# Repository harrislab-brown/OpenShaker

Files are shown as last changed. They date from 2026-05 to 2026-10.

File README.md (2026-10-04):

# OpenShaker

OpenShaker is a low-cost, flexure-guided vibration platform for fluid-mechanics experiments. It uses an affordable base shaker, a compliant stinger, and two disk flexures to reduce unwanted horizontal motion so that the bath moves predominantly in the vertical direction.

The project is designed to be reproducible and adaptable. This repository contains the 3D-print files, mechanical models, flexure geometry, control and analysis code, parts information, and build documentation needed to reproduce the current system.

<p align="center">
  Assembled OpenShaker system
</p>

> [!WARNING]
> OpenShaker combines moving hardware, a power amplifier, fabricated spring-steel flexures, power tools, and nearby liquids. Read the [safety guidance](https://github.com/harrislab-brown/OpenShaker/wiki/1.-Safety) before fabrication or operation. Inspect and tighten the assembly before every run, keep electronics dry, know how to stop the amplifier and software quickly, and begin new tests with conservative settings.

## How the system works

1. A 50 W base shaker, driven by an external amplifier, supplies the vibration.
2. A thin music-wire stinger transfers vertical motion while remaining compliant in the horizontal plane.
3. Two spiral disk flexures guide the bath assembly and resist planar motion.
4. Two bath-mounted LSM6DS3 accelerometers measure the response at separate locations.
5. A VibeCheck controller and the supplied Python code adjust drive amplitude to reach a target Bath 1 Z-axis acceleration while recording both sensors for later comparison.

This arrangement is intended to provide a defined and repeatable input for experiments involving vertically forced fluids. It is a research platform under active development, not a calibrated commercial vibration table.

## Start here

The [OpenShaker wiki](https://github.com/harrislab-brown/OpenShaker/wiki) contains the complete build and operating instructions. New users should follow the pages in this order:

1. [Safety](https://github.com/harrislab-brown/OpenShaker/wiki/1.-Safety)
2. [Required Tools](https://github.com/harrislab-brown/OpenShaker/wiki/2.-Required-Tools)
3. [Complete Parts List](https://github.com/harrislab-brown/OpenShaker/wiki/3.-Complete-Parts-List)
4. [3D Printing Guide](https://github.com/harrislab-brown/OpenShaker/wiki/4.-3D-Printing-Guide)
5. [Aluminum Extrusion and Bass Shaker Preparation](https://github.com/harrislab-brown/OpenShaker/wiki/5.-Aluminum-Extrusion-and-Bass-Shaker-Preparation)
6. [Laser Cutting the Disk Flexures](https://github.com/harrislab-brown/OpenShaker/wiki/6.-Laser-Engraving-for-Disk-Flexure-Cutting)
7. [Shaker Assembly Guide](https://github.com/harrislab-brown/OpenShaker/wiki/7.-Shaker-Assembly-Guide)
8. [Python, PID, and Plotting Overview](https://github.com/harrislab-brown/OpenShaker/wiki/8.-Python,-PID,-and-Plotting-Overview)
9. [Shaker Performance](https://github.com/harrislab-brown/OpenShaker/wiki/9.-Shaker-Performance)
10. [Ideas and Future Work](https://github.com/harrislab-brown/OpenShaker/wiki/9.1-Ideas-and-Future-Work)

## Repository contents

| Location | Contents |
| --- | --- |
| [`3D Print STLs`](https://github.com/harrislab-brown/OpenShaker/tree/main/3D%20Print%20STLs) | Individual printable parts |
| [`Bambu Print Files`](https://github.com/harrislab-brown/OpenShaker/tree/main/Bambu%20Print%20Files) | Prepared Bambu Studio project files and build plates |
| [`Code`](https://github.com/harrislab-brown/OpenShaker/tree/main/Code) | Current sweep-control, data-collection, setup, and plotting scripts |
| [`Flexure Files`](https://github.com/harrislab-brown/OpenShaker/tree/main/Flexure%20Files) | Disk-flexure geometry for fabrication |
| [`Fusion Files`](https://github.com/harrislab-brown/OpenShaker/tree/main/Fusion%20Files) | Editable mechanical design files |
| [`accelerometer_3_files)`](https://github.com/harrislab-brown/OpenShaker/tree/main/accelerometer_3_files) | Experimental three-sensor data-collection work |
| [Wiki](https://github.com/harrislab-brown/OpenShaker/wiki) | Parts, fabrication, assembly, software, safety, and performance documentation |

## Software quick start

Go to 8. [Python, PID, and Plotting Overview](https://github.com/harrislab-brown/OpenShaker/wiki/8.-Python,-PID,-and-Plotting-Overview)

## Documented performance configuration

The comparison sweeps currently published in the wiki use the following configuration:

| Component or setting | Reference value |
| --- | --- |
| Flexures | Two three-arm spiral flexures, 180° relative orientation |
| Flexure material | 1095 blue-tempered spring steel, 0.010 in (0.254 mm) thick |
| Stinger | 100 mm of 0.033 in music wire |
| Threaded support rod | 110 mm long, 1/4 in diameter |
| Standard bath | 100 mm, approximately 0.070 kg total moving bath mass |
| Sensors | Two LSM6DS3 accelerometers on the bath assembly |
| Example sweep | 25–300 Hz in 5 Hz increments, 5000 Hz sensor rate, 1.0 G peak target |

## Fabrication notes

- The frame uses 2020 aluminum extrusion. The documented cut list includes four 400 mm columns and fourteen 190 mm horizontal or shelf members.
- The standard build uses 19 unique printed part types and 32 required printed pieces, or 34 when both optional pieces are included.
- The original flexures were cut from 0.010 in 1095 blue-tempered spring steel using the supplied 60 mm disk-flexure geometry.
- Flexure material, thickness, cutting quality, bath mass, and assembly alignment can all change the system response. Treat substitutions as new configurations that require cautious testing.

## Data produced by a sweep

The PID script creates a timestamped CSV containing:

- sample time;
- commanded frequency and drive amplitude;
- sensor channel (`0` for Bath 1 and `2` for Bath 2); and
- raw X-, Y-, and Z-axis acceleration in G.

The plotting script groups the data by frequency, calculates AC RMS response, compares the two Z-axis measurements, evaluates combined planar motion, and reports the planar-to-Z ratio. It also saves high-resolution sweep plots and paginated time traces.

## Project status and support

OpenShaker is under active development. The wiki describes the current two-bath-sensor workflow; the `THIRD SENSOR (Data Collection)` folder contains separate experimental work. Check the script settings and wiki before building or running the system because filenames, procedures, and reference configurations may continue to change.

If you find an error or have a reproducibility problem, [open a GitHub issue](https://github.com/harrislab-brown/OpenShaker/issues) and include:

- the step or script you were using;
- your operating system and Python version;
- the mechanical configuration and test settings; and
- the complete error message or relevant data figure.

## License

A project license has not yet been added to this repository. Until one is included, contact the maintainers before redistributing or adapting the project files.

## Acknowledgments

OpenShaker is being developed by the [Harris Lab at Brown University](https://github.com/harrislab-brown). The control and measurement workflow uses the VibeCheck platform.

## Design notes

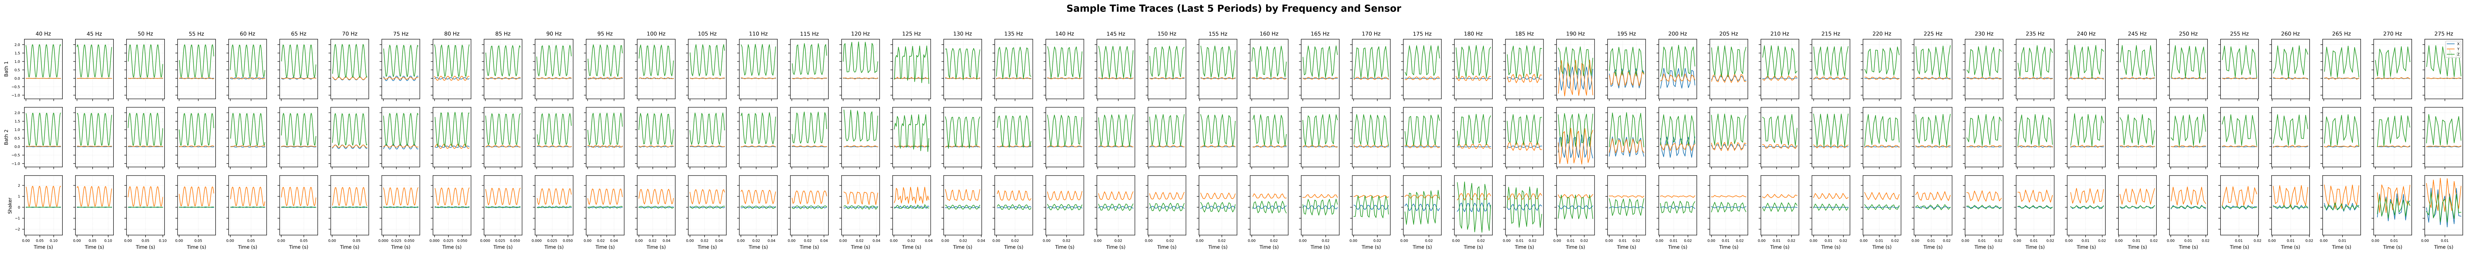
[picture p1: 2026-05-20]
Code/PID2/2026-05-20_13-20-33_v1.1-1.1 (lower amp.)_vibecheck_sweep_40-300Hz_840Hz_1.0G_360LF_0.27kg_Stinger_80mm_time_traces.png

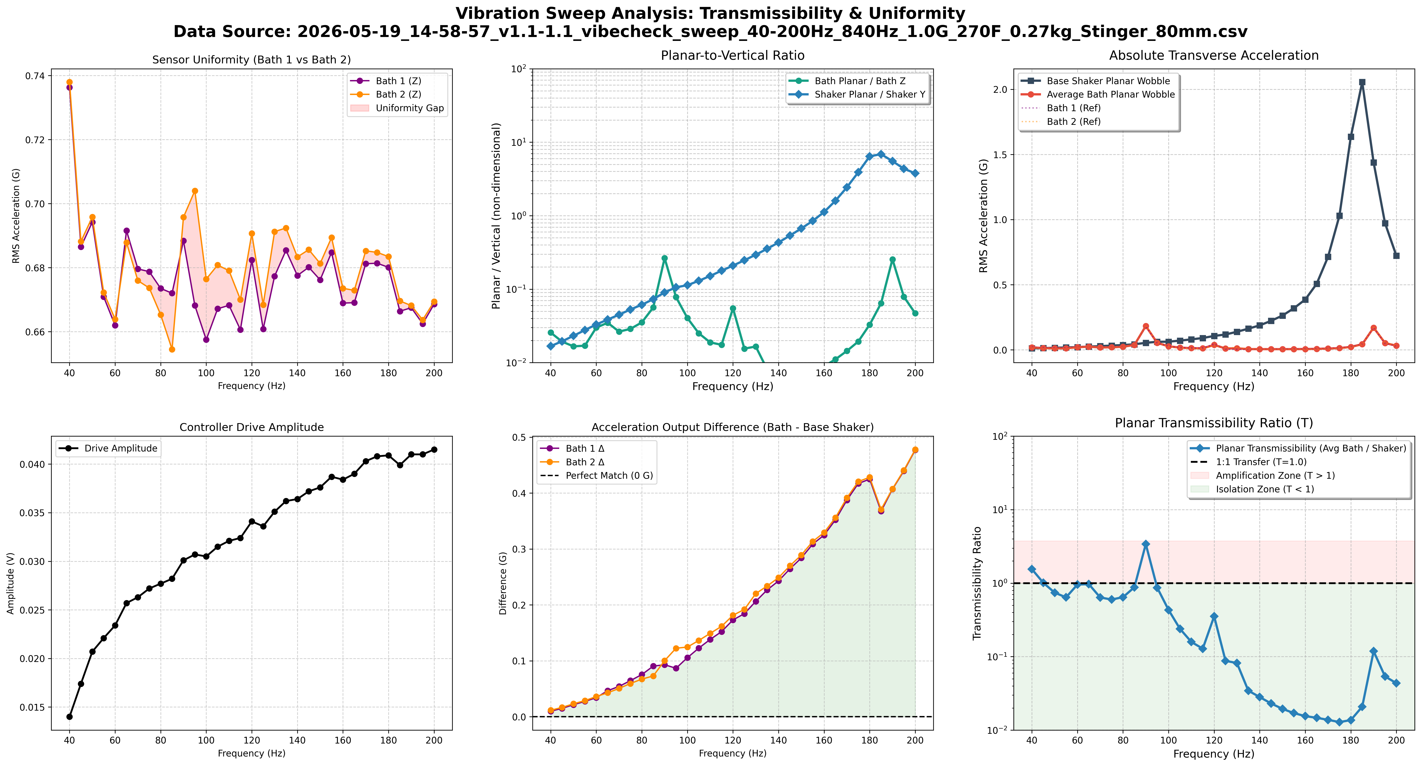
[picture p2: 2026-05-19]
Code/PID/2026-05-19_14-58-57_v1.1-1.1_vibecheck_sweep_40-200Hz_840Hz_1.0G_270F_0.27kg_Stinger_80mm.png

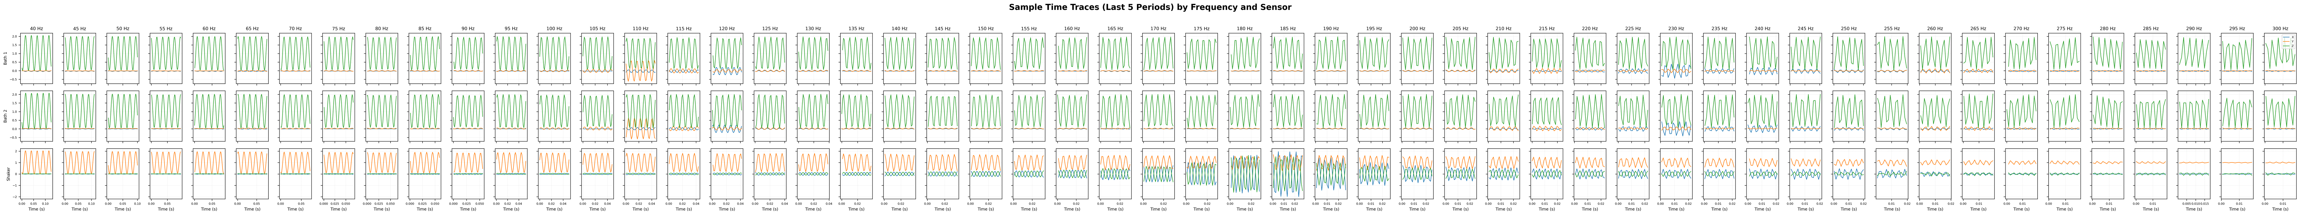
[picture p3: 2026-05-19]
Code/PID2/2026-05-19_15-26-36_v1.1-1.1_vibecheck_sweep_40-300Hz_840Hz_1.0G_270F_0.135kg_Stinger_80mm_time_traces.png

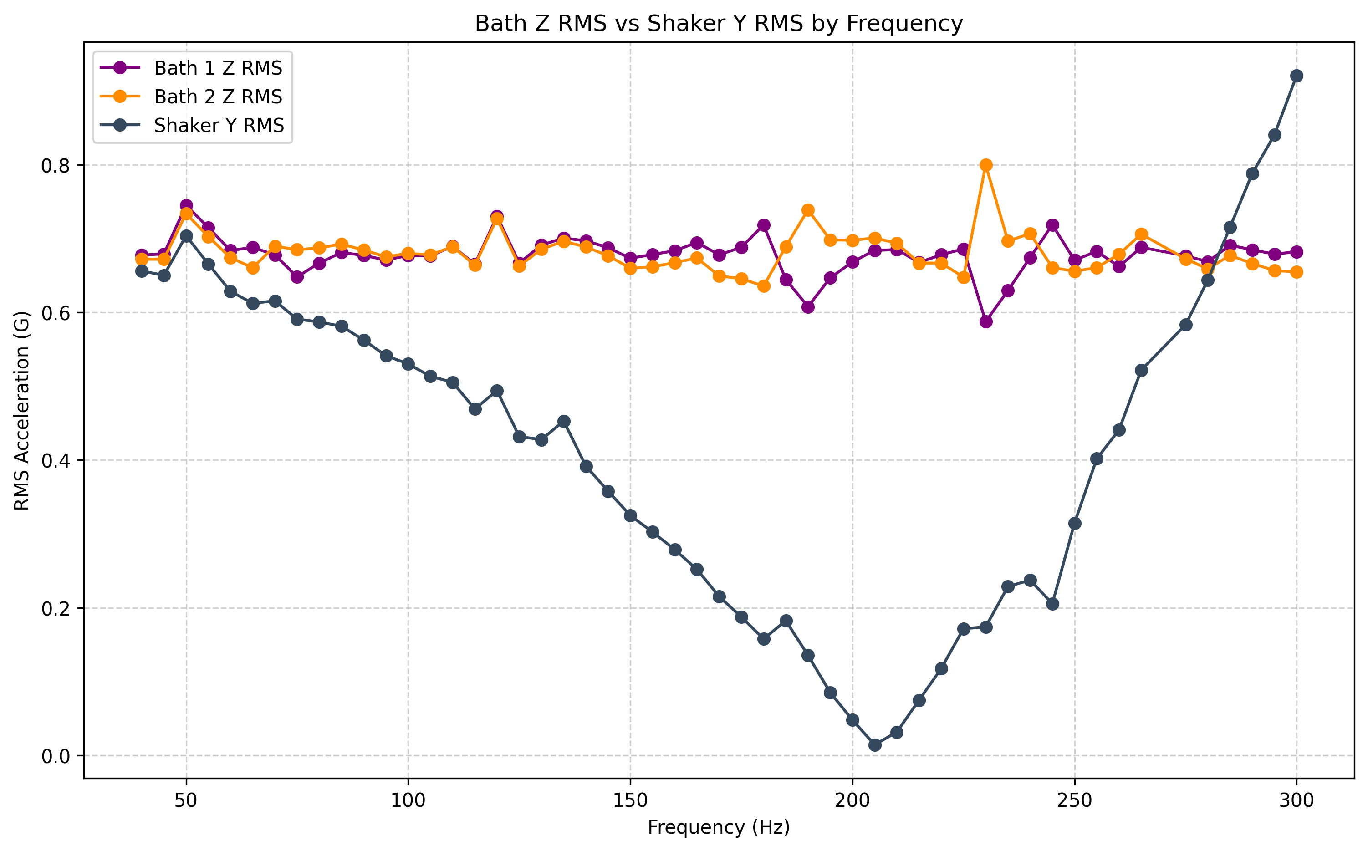
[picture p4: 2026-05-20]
Code/PID2/2026-05-20_08-00-56_v1.1-1.1_vibecheck_sweep_40-300Hz_840Hz_1.0G_360F_0.27kg_Stinger_80mm_bath_z_vs_shaker_y.png

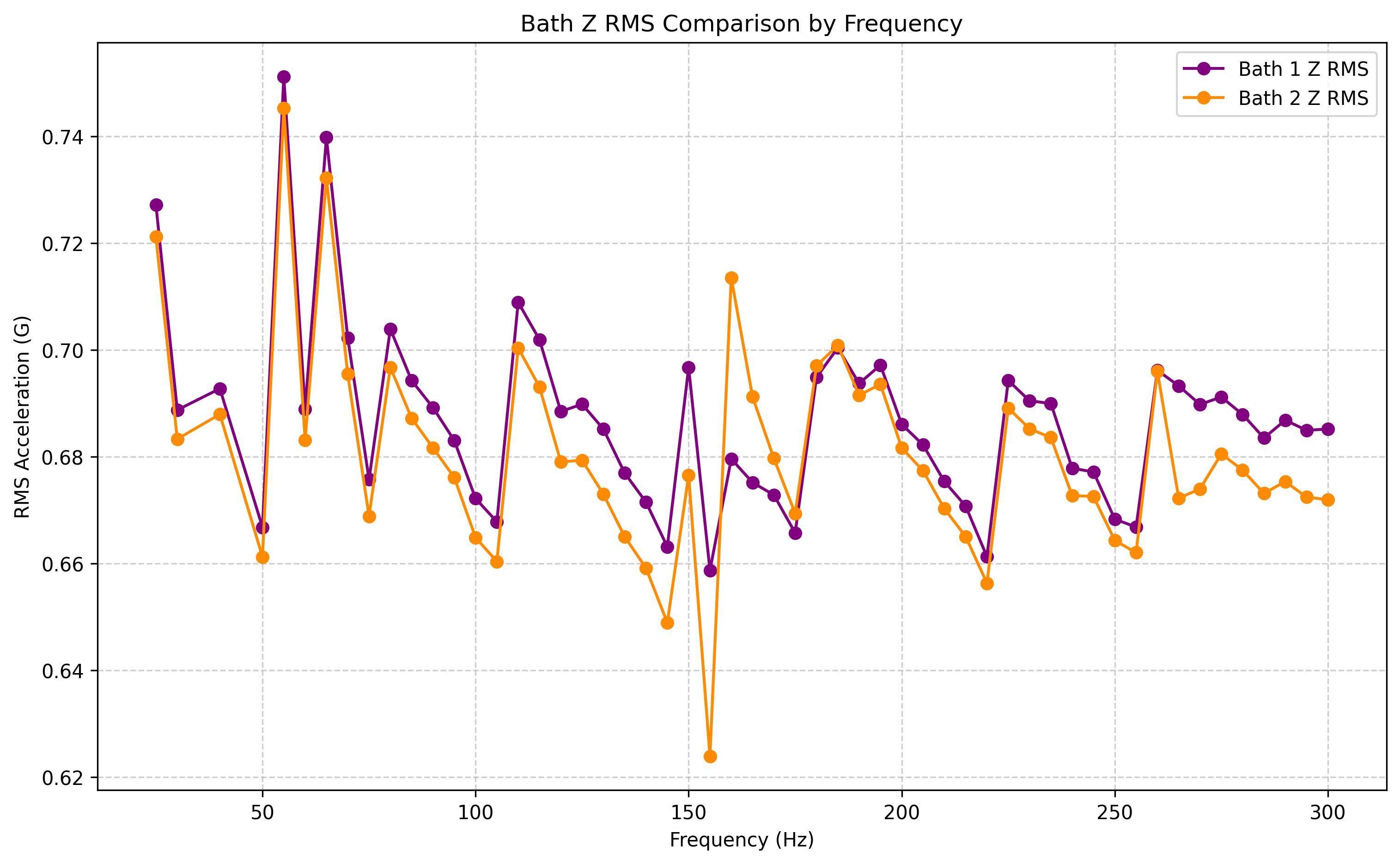
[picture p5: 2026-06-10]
Code/PID2/2026-06-08_17-11-16_v1.2-1.4_vibecheck_sweep_25-300Hz_840Hz_1.0G_180F_0.07kg_Total_Stinger_100mm_Spacer_10mm_bath_z_comparison.png

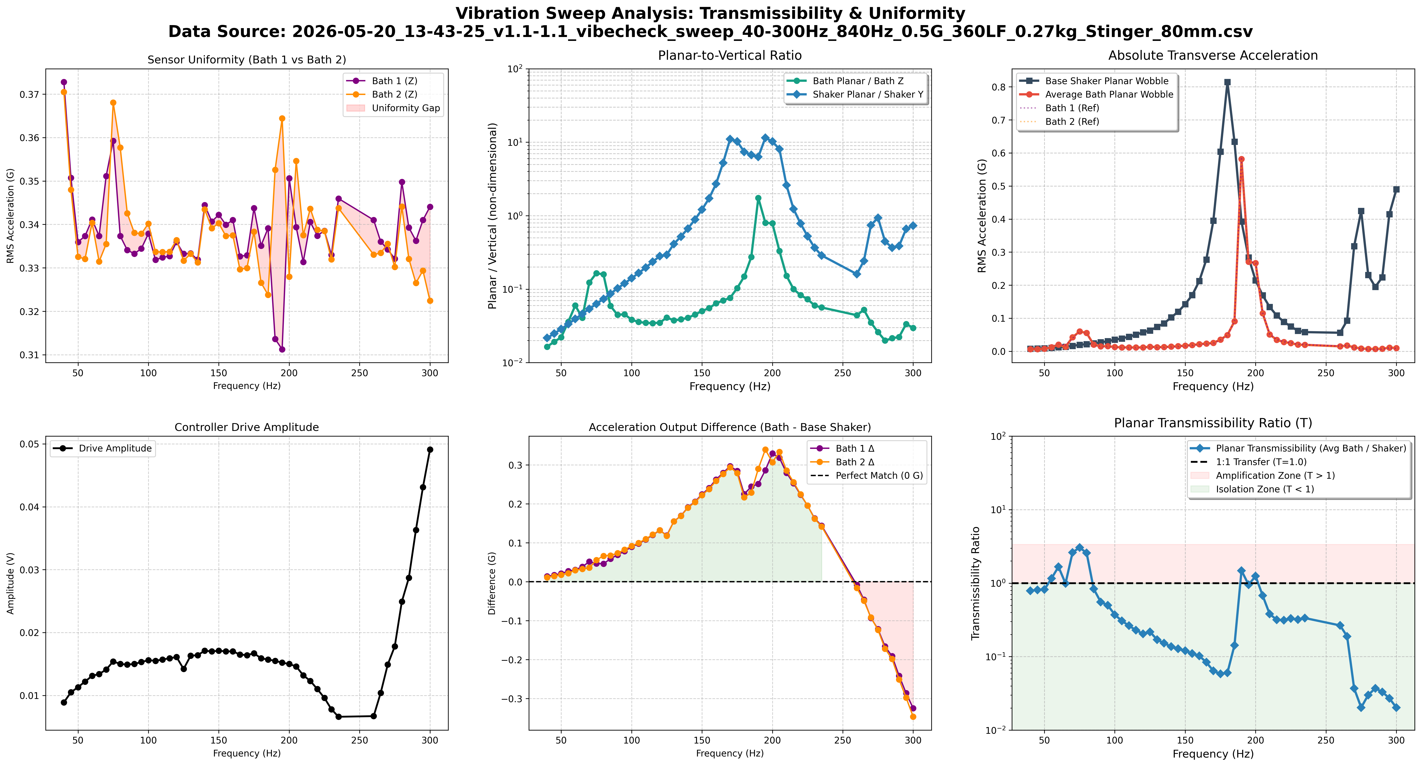
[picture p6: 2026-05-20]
Code/PID/2026-05-20_13-43-25_v1.1-1.1_vibecheck_sweep_40-300Hz_840Hz_0.5G_360LF_0.27kg_Stinger_80mm.png

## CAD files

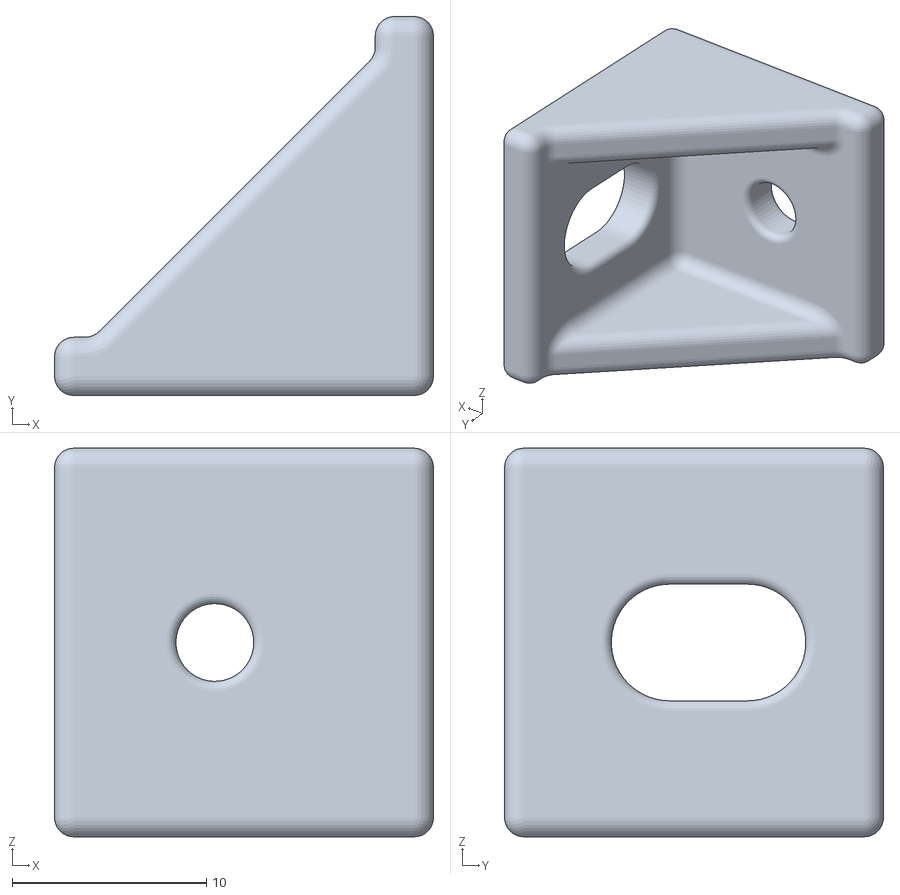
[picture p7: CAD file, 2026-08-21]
3D Print STLs/1) Custom PLA Corner Bracket.stl
19.5 x 19.5 x 20.0

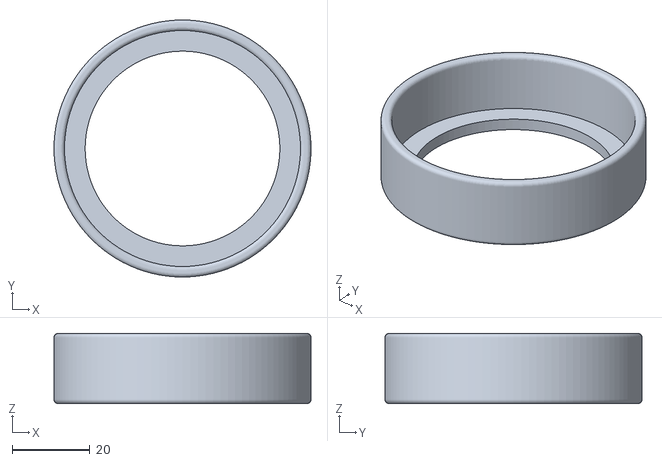
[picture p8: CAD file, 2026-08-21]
3D Print STLs/16) PLA Flexure Housing Ring 0.2mm Offset S2/16) PLA Flexure Housing Ring 0.3mm Offset S2.stl
66.0 x 66.0 x 18.0

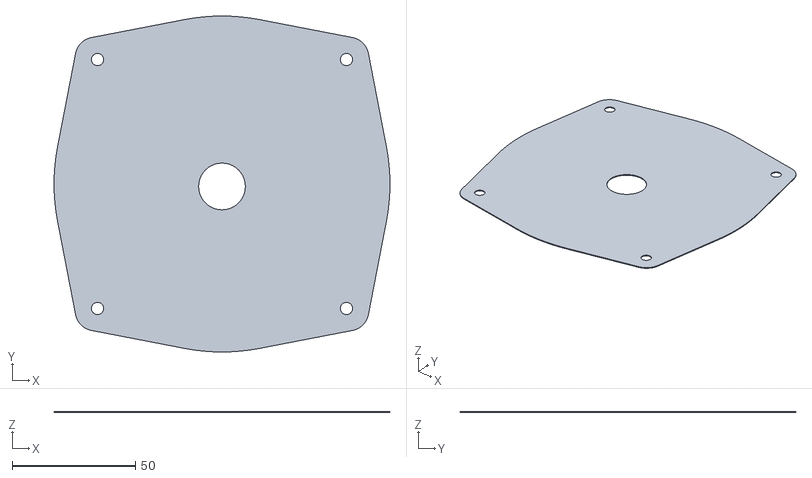
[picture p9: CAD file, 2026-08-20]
3D Print STLs/2) PLA Decorative Base Shaker Cover/2.Solid) PLA Decorative Base Shaker Cover.stl
136.5 x 136.5 x 0.4

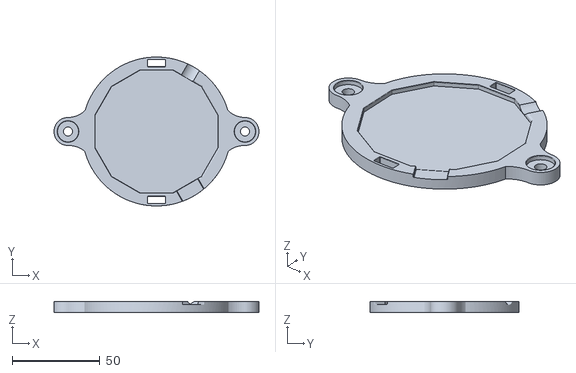
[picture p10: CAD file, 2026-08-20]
3D Print STLs/5) PLA VibeCheck Mount/5.Solid) PLA VibeCheck Mount.stl
117.0 x 85.0 x 6.00

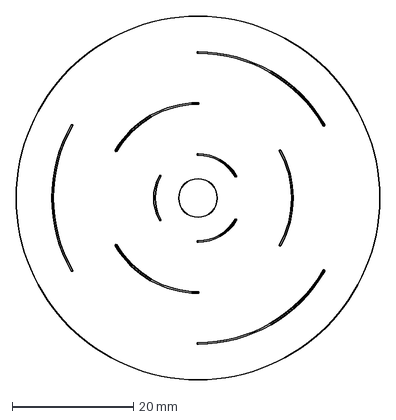
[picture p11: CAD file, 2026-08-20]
Flexure Flies/60x3 Concentric Flexure.dxf
60.0 x 60.0 mm

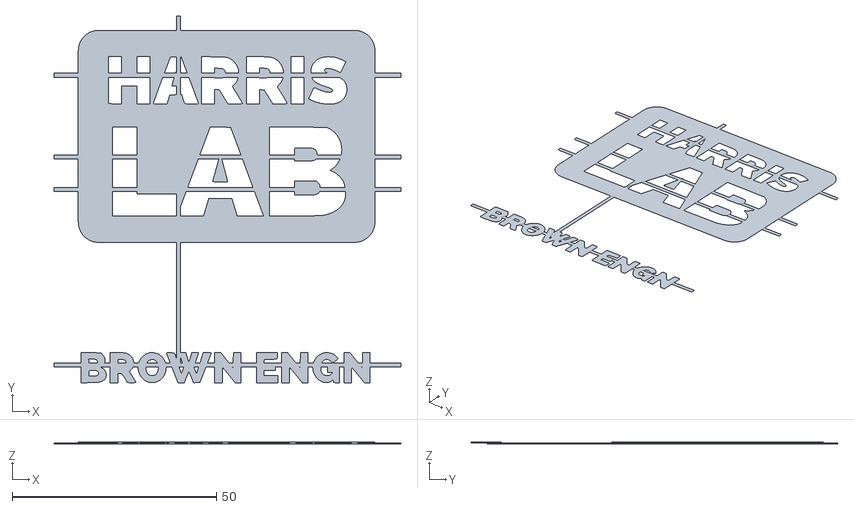
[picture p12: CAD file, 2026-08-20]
3D Print STLs/2) PLA Decorative Base Shaker Cover/2.2) PLA Decorative Base Shaker Cover.stl
85.0 x 89.9 x 0.4

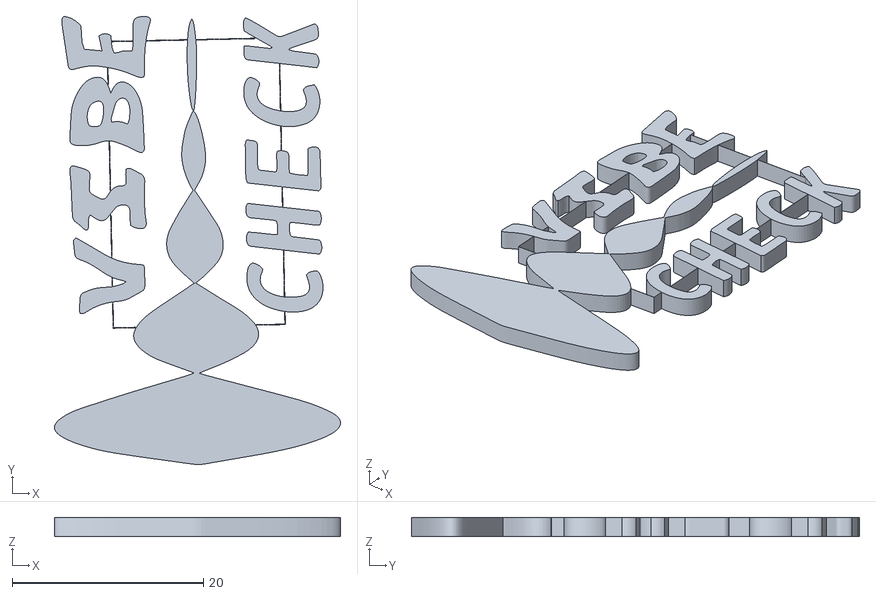
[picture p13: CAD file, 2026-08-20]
3D Print STLs/5) PLA VibeCheck Mount/5.2) PLA VibeCheck Mount.stl
30.0 x 46.9 x 2.00

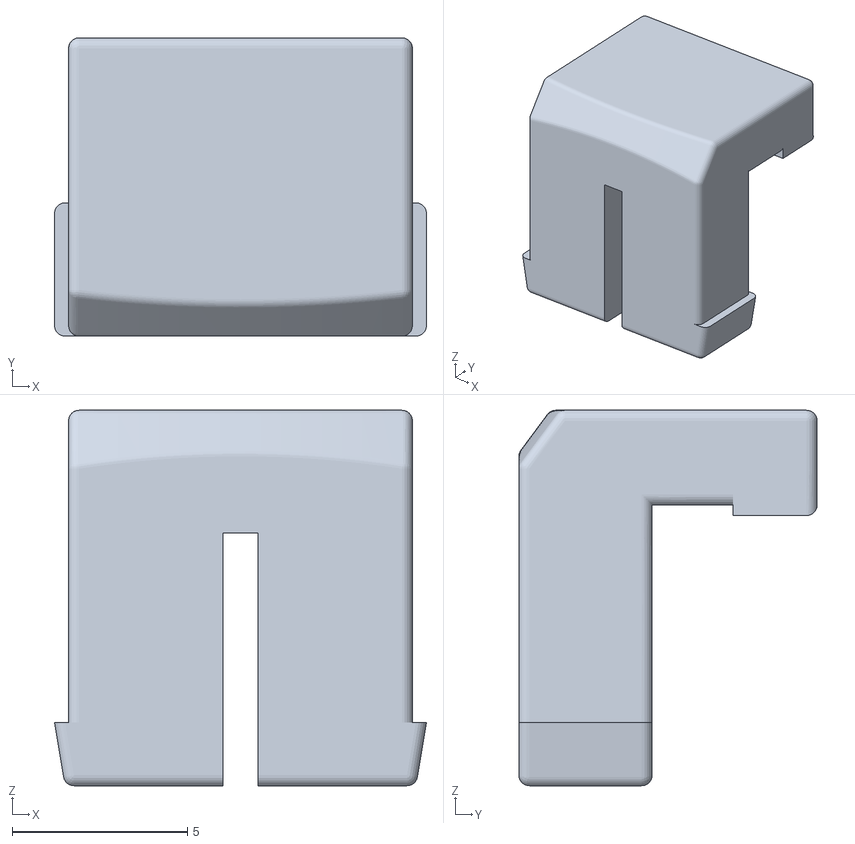
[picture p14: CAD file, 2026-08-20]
3D Print STLs/6) PLA VibeCheck Mount Clips.stl
10.6 x 8.50 x 10.7

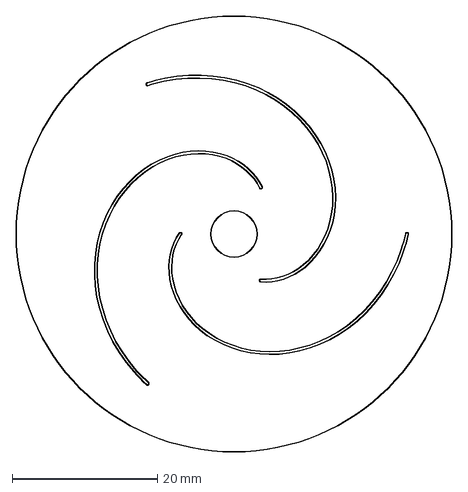
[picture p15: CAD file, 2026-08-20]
Flexure Flies/180 Flexure.dxf
60.0 x 60.0 mm

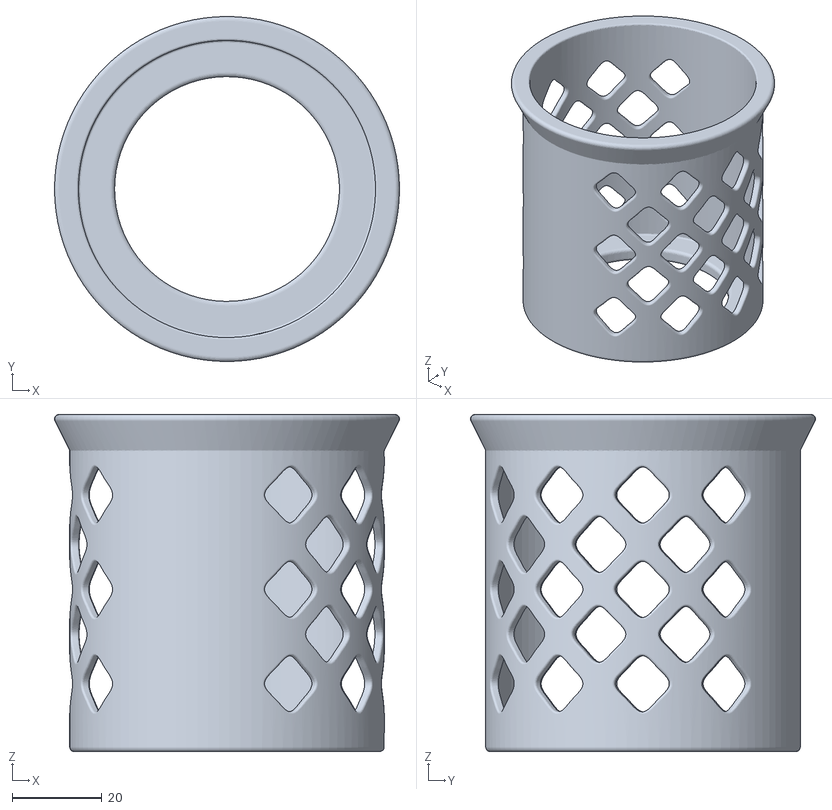
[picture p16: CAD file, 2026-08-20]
3D Print STLs/14) PLA Flexure Housing Base.stl
76.8 x 76.8 x 75.0

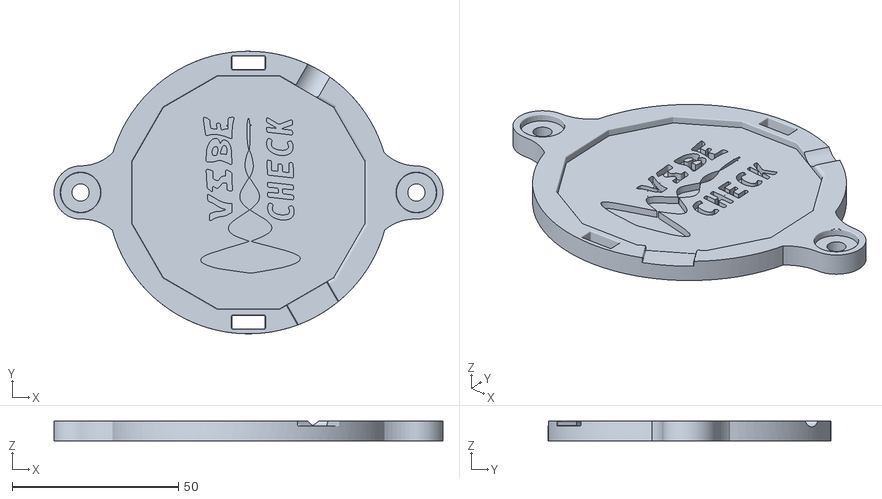
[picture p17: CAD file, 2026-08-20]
3D Print STLs/5) PLA VibeCheck Mount/5.1) PLA VibeCheck Mount.stl
117.0 x 85.0 x 6.00

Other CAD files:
Bambu Print Files/Plates/Plate 5.gcode.3mf
3D Print STLs/16) PLA Flexure Housing Ring 0.2mm Offset S2/16) PLA Flexure Housing Ring 0.2mm Offset S2.stl
Bambu Print Files/Individual Parts/9) PLA Extrusion Feet Attachments.gcode.3mf
Bambu Print Files/Plates/Plate 2.gcode.3mf
3D Print STLs/2) PLA Decorative Base Shaker Cover/2.1) PLA Decorative Base Shaker Cover.stl
Bambu Print Files/Individual Parts/16) PLA Flexure Housing Ring 0.2mm Offset S2.gcode.3mf
Bambu Print Files/Plates/Plate 3.gcode.3mf
3D Print STLs/10) PLA Base Shaker Attachment.stl
3D Print STLs/11) PLA Base Shaker-Stinger Attachment.stl
3D Print STLs/12) PLA Stinger-Rod Attachment.stl
3D Print STLs/13) PLA Flexure Housing Base.stl
3D Print STLs/15) PLA Flexure Housing Column.stl
3D Print STLs/17) PLA Flexure Housing Screw Clamp.stl
3D Print STLs/18) PLA Bath Adapter with Accelerometer Attachments.stl
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

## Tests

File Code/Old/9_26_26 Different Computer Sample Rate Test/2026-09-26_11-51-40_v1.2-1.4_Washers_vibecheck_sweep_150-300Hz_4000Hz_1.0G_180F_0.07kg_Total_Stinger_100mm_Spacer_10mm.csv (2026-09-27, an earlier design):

Timestamp | Freq | Drive_Amp | Channel | X | Y | Z
1249.016566 | 150 | 0.0296 | 0 | -0.062 | -0.09 | -0.638
1249.016708 | 150 | 0.0296 | 2 | 0.027 | 0.069 | -0.415
1249.016855 | 150 | 0.0296 | 0 | -0.033 | -0.056 | -0.388
1249.016996 | 150 | 0.0296 | 2 | 0.003 | 0.027 | -0.22
1249.017145 | 150 | 0.0296 | 0 | -0.012 | -0.016 | -0.176
1249.017285 | 150 | 0.0296 | 2 | -0.028 | -0.02 | -0.073
1249.017436 | 150 | 0.0296 | 0 | 0.019 | 0.03 | -0.032
1249.017574 | 150 | 0.0296 | 2 | -0.056 | -0.06 | -0.005
1249.017726 | 150 | 0.0296 | 0 | 0.05 | 0.068 | 0.049
1249.017862 | 150 | 0.0296 | 2 | -0.077 | -0.108 | -0.001
1249.018016 | 150 | 0.0296 | 0 | 0.071 | 0.103 | 0.05
1249.018151 | 150 | 0.0296 | 2 | -0.098 | -0.14 | -0.073
1249.018306 | 150 | 0.0296 | 0 | 0.088 | 0.136 | -0.023
1249.01844 | 150 | 0.0296 | 2 | -0.117 | -0.161 | -0.205
1249.018596 | 150 | 0.0296 | 0 | 0.094 | 0.158 | -0.166
1249.018728 | 150 | 0.0296 | 2 | -0.125 | -0.172 | -0.389
1249.018886 | 150 | 0.0296 | 0 | 0.094 | 0.166 | -0.375
1249.019017 | 150 | 0.0296 | 2 | -0.129 | -0.17 | -0.622
1249.019176 | 150 | 0.0296 | 0 | 0.085 | 0.167 | -0.626
1249.019306 | 150 | 0.0296 | 2 | -0.119 | -0.15 | -0.882
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

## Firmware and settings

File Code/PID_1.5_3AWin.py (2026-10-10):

"""Two-stream, three-accelerometer vibration sweep.

Each frequency: tune mean bath Z AC RMS -> BATH_PAIR (channels 0/2)
-> stop Bath 2 -> start shaker -> SHAKER_PAIR (channels 0/4).
Frequency and commanded amplitude are frozen across both capture blocks and
switching. Bath 1 remains streaming. Stop/start are firmware commands, not
Python-side filtering. The supplied firmware powers down the inactive accel.

CSV starts with the original seven columns. Step, Phase, Timestamp_us,
Window_Start_us and Window_End_us identify paired measurement blocks.
Raw X/Y/Z and device timestamps are preserved, never remapped or reset.
Capture windows use the SAME device-time bounds for both members of a pair.
This requires a common, monotonic device microsecond clock; Python cannot
provide hardware sample synchronization. Sequential blocks are not simultaneous.

Shaker vertical is provisionally Y; its planar axes are X/Z. Bath vertical
is Z and planar axes are X/Y. Verify mounting before interpreting results.
Rate-check revision: reads the configured ODR back, sizes RMS windows using it,
uses a 5 ms acquisition timer and 10 Hz plotting, stops unused gyro/fake streams,
and saves detailed diagnostics on failure. It does NOT reorder/drop samples or
rewrite timestamps. This may help host-side backlog, not repair firmware data.
CSV rates are configured nominal rates, not measured achieved sample rates.
Dependencies: pip install pyserial numpy matplotlib
P: pause progression AFTER both blocks (drive continues); P again resumes.
S: skip during tuning only; Q or close window: stop everything.
"""
import csv
import datetime
import math
import re
import time
from collections import deque

import serial
import numpy as np
import matplotlib.pyplot as plt

# --- EXISTING EXPERIMENT SETTINGS ---
PORT = 'COM5'
BAUD_RATE = 115200
SWEEP_START_FREQ = 25
SWEEP_END_FREQ = 300
SWEEP_STEP_SIZE = 5
TARGET_PEAK_G = 1.0
MAX_AMPLITUDE = 0.8
TOLERANCE_PCT = 0.07
STABILITY_WINDOW = 3.0
UPDATE_INTERVAL = 0.25
COLLECT_TIME_SEC = 3.0       # Per pair: 3 seconds + 3 seconds at each frequency.
WINDOW_SIZE = 100
CONTROL_WINDOW_SEC = 0.25  # Keep the RMS estimate long enough as ODR increases.
ODR_SETTING = 3330  # Up to 4995Hz the PID will run, but it will record at 3330Hz.
READ_INTERVAL_MS = 5
PLOT_INTERVAL_SEC = 0.10  # Plot less often than serial polling.
SHOW_LIVE_PLOT = True    # False keeps status/controls but avoids waveform rendering.
BMASS = 0.070
DEGREE = '180'
STINGER_LENGTH = 100
SPACER = 10
APP_VERSION = '1.5_3Accel_Paired_RateCheck'
PHYS_VERSION = '1.5'

# Command port and streamed channel ID are different identifiers.
SENSOR_PORT_TO_CHANNEL = {0: 0, 1: 2, 2: 4}
CHANNEL_TO_PORT = {ch: port for port, ch in SENSOR_PORT_TO_CHANNEL.items()}
CHANNEL_LABELS = {0: 'Bath 1', 2: 'Bath 2', 4: 'Base shaker'}
BATH_PAIR = (0, 2)
SHAKER_PAIR = (0, 4)        # Bath 1 is retained throughout each frequency step.
SHAKER_VERTICAL_AXIS = 'y'
VERTICAL_AXES = {0: 'z', 2: 'z', 4: SHAKER_VERTICAL_AXIS}
# Mean of the two individual Z-axis AC RMS values, NOT RMS of averaged traces.
# Set to (0,) to restore the previous Bath-1-only feedback definition.
FEEDBACK_CHANNELS = BATH_PAIR
STREAM_START_TIMEOUT_SEC = 10.0
STREAM_STALE_TIMEOUT_SEC = 2.0
SWITCH_QUIET_SEC = 0.15     # Observe old stream stop BEFORE enabling its replacement.
SWITCH_SETTLE_SEC = 0.25    # Refill incoming stream before opening a capture window.
DRIVE_SETTLE_SEC = 0.5
MIN_START_SAMPLES = 20
# This is a gross clock/backlog check, not a claim of sample-level synchronization.
MAX_PAIR_CLOCK_SKEW_SEC = 0.1


def build_csv_filename():
    timestamp = datetime.datetime.now().strftime('%Y-%m-%d_%H-%M-%S')
    return (f'{timestamp}_v{APP_VERSION}-{PHYS_VERSION}_vibecheck_sweep_'
            f'{SWEEP_START_FREQ}-{SWEEP_END_FREQ}Hz_req{ODR_SETTING}Hz_'
            f'{TARGET_PEAK_G}G_{DEGREE}F_{BMASS}kg_'
            f'Total_Stinger_{STINGER_LENGTH}mm_Spacer_{SPACER}mm.csv')


def get_ac_rms(values):
    return float(np.std(values)) if len(values) >= MIN_START_SAMPLES else 0.0


class Acquisition:
    """One serial reader for replies and data, including during stream switches."""
    def __init__(self, device, clock=time.monotonic):
        self.device, self.clock = device, clock
        self.buffer = bytearray()
        self.replies = deque(maxlen=100)
        buffer_size = max(WINDOW_SIZE, math.ceil(ODR_SETTING * CONTROL_WINDOW_SEC))
        self.data = {ch: {axis: deque(maxlen=buffer_size) for axis in 'xyzt'}
                     for ch in CHANNEL_LABELS}
        self.last_received = {ch: None for ch in CHANNEL_LABELS}
        self.last_timestamp = {ch: None for ch in CHANNEL_LABELS}
        self.samples = {ch: 0 for ch in CHANNEL_LABELS}
        self.on_sample = None
        self.allowed_channels = set(CHANNEL_LABELS)  # Startup stop/drain only.
        self.shut_down = False
        self.initializing = True
        self.configured_odr = {}
        self.recent_records = deque(maxlen=16)
        self.max_backlog_bytes = 0
        self.last_wire_time = self.clock()
        self.diagnostic_path = None

    def send(self, command):
        self.device.write((command + '\n').encode('utf-8'))

    def command(self, command, timeout=1.5):
        self.poll()
        self.replies.clear()
        print(f'Sending: {command}')
        self.send(command)
        deadline = self.clock() + timeout
        while self.clock() < deadline:
            self.poll()
            while self.replies:
                reply = self.replies.popleft()
                if re.search(r'\b(error|fail|failed|invalid)\b', reply, re.I):
                    raise RuntimeError(f'{command}: {reply}')
                if re.search(r'\b(ack|ok)\b', reply, re.I):
                    print(f'   -> Board: {reply}')
                    return reply
            time.sleep(0.005)
        raise RuntimeError(f'No ACK/OK for command: {command}')

    def clear_traces(self, channels):
        for ch in channels:
            for values in self.data[ch].values():
                values.clear()

    def poll(self):
        waiting = self.device.in_waiting
        self.max_backlog_bytes = max(self.max_backlog_bytes, waiting)
        self.buffer.extend(self.device.read(min(waiting, 262144)))
        if len(self.buffer) > 1048576:
            raise RuntimeError('Serial input has no valid line endings.')
        lines = self.buffer.split(b'\n')
        self.buffer[:] = lines.pop()
        for raw_line in lines:
            line = raw_line.decode('utf-8', errors='strict').strip()
            parts = line.split()
            if not parts:
                continue
            if parts[0] != 'data':
                self.replies.append(line)
                if re.search(r'\b(error|failed|invalid)\b', line, re.I):
                    raise RuntimeError(f'Board reported: {line}')
                continue
            self.last_wire_time = self.clock()
            # Discard residual packets ONLY while startup stops/drains all streams.
            # Updating last_wire_time above still requires a quiet drain period.
            # Normal packet/timestamp validation resumes before sensors are started.
            if self.initializing:
                continue
            try:
                count = int(parts[1])
                if count < 0 or len(parts) != 2 + 5 * count:
                    raise ValueError('wrong packet length')
                records = []
                for i in range(count):
                    idx = 2 + 5 * i
                    ch, timestamp = int(parts[idx]), int(parts[idx + 1])
                    xyz = tuple(float(v) for v in parts[idx + 2:idx + 5])
                    if timestamp < 0 or not all(math.isfinite(v) for v in xyz):
                        raise ValueError('invalid measurement')
                    records.append((ch, timestamp, xyz))
            except (ValueError, IndexError) as error:
                raise RuntimeError(f'Malformed data packet: {error}') from error
            for ch, timestamp, xyz in records:
                if ch not in self.data:
                    if not self.initializing:
                        raise RuntimeError(f'Unexpected data channel {ch}; unused streams should be stopped')
                    continue
                if ch not in self.allowed_channels:
                    raise RuntimeError(f'Inactive channel {ch} is still transmitting; '
                                       'cannot maintain two-stream acquisition.')
                old = self.last_timestamp[ch]
                if old is not None and timestamp <= old:
                    context = list(self.recent_records) + [(ch, timestamp, xyz)]
                    raise RuntimeError(
                        f'Channel {ch}: previous={old} us, new={timestamp} us, '
                        f'change={timestamp - old} us; requested ODR={ODR_SETTING}, '
                        f'configured ODR={self.configured_odr.get(ch, "unknown")}; '
                        f'current backlog={self.device.in_waiting} bytes, '
                        f'max observed backlog={self.max_backlog_bytes} bytes; '
                        f'recent raw records (channel, timestamp_us, XYZ)={context}')
                self.recent_records.append((ch, timestamp, xyz))
                self.last_timestamp[ch] = timestamp
                self.last_received[ch] = self.clock()
                self.samples[ch] += 1
                for axis, value in zip('xyz', xyz):
                    self.data[ch][axis].append(value)
                self.data[ch]['t'].append(timestamp / 1e6)
                if self.on_sample is not None:
                    self.on_sample(ch, timestamp, xyz)

    def initialize(self):
        # Stop ALL streams first; never start all three for discovery.
        self.send('wavegen stop')
        self.send('sensor fakedata stop')
        for port in SENSOR_PORT_TO_CHANNEL:
            self.send(f'sensor {port} stop accel')
            self.send(f'sensor {port} stop gyro')
        started = self.clock()
        deadline = started + STREAM_START_TIMEOUT_SEC
        while True:
            self.poll()
            latest = max([started, self.last_wire_time] + [v for v in self.last_received.values()
                                      if v is not None])
            if self.clock() - latest >= SWITCH_QUIET_SEC and not self.device.in_waiting:
                break
            if self.clock() >= deadline:
                raise RuntimeError('Sensors did not stop during initialization.')
            time.sleep(0.005)
        self.allowed_channels.clear()
        self.initializing = False
        for port in SENSOR_PORT_TO_CHANNEL:
            self.command(f'sensor {port} set accel range 8')
            self.command(f'sensor {port} set accel odr {ODR_SETTING}')
            reply = self.command(f'sensor {port} get accel odr')
            match = re.fullmatch(r'(?:ack|ok)\s+(\d+)', reply.strip(), re.I)
            if not match or int(match.group(1)) <= 0:
                raise RuntimeError(f'Cannot verify configured ODR for sensor port {port}: {reply}')
            rate = int(match.group(1))
            ch = SENSOR_PORT_TO_CHANNEL[port]
            self.configured_odr[ch] = rate
            size = max(WINDOW_SIZE, math.ceil(rate * CONTROL_WINDOW_SEC))
            self.data[ch] = {axis: deque(maxlen=size) for axis in 'xyzt'}
            print(f'CHANNEL {ch}: requested {ODR_SETTING} Hz; board configured {rate} Hz')
        if len(set(self.configured_odr.values())) != 1:
            raise RuntimeError(f'Sensors report different ODRs: {self.configured_odr}')
        self.command('wavegen set waveform sine')
        self.clear_traces(CHANNEL_LABELS)
        # Configure does not prove the requested ODR is the actual hardware rate.

    def shutdown(self):
        if self.shut_down:
            return
        self.shut_down = True
        errors = []
        for command in ['wavegen stop', 'sensor fakedata stop'] + [f'sensor {p} stop {kind}'
                                          for p in SENSOR_PORT_TO_CHANNEL for kind in ('accel', 'gyro')]:
            try:
                self.send(command)
            except Exception as error:
                errors.append(f'{command}: {error}')
        if errors:
            print('Shutdown command errors: ' + '; '.join(errors))


class PairSwitcher:
    """Stop, verify silence, then start; no waveform commands are issued here."""
    def __init__(self, acquisition):
        self.a = acquisition
        self.active = set()
        self.target = ()
        self.state = 'IDLE'
        self.started = 0.0
        self.ready_since = None

    def request(self, pair):
        if self.state not in ('IDLE', 'READY'):
            raise RuntimeError('Pair switch already in progress')
        if len(pair) != 2 or len(set(pair)) != 2:
            raise ValueError('Exactly two distinct channels are required')
        self.target = tuple(pair)
        self.leaving = self.active - set(pair)
        self.joining = set(pair) - self.active
        self.started = self.a.clock()
        self.ready_since = None
        for ch in self.leaving:
            self.a.send(f'sensor {CHANNEL_TO_PORT[ch]} stop accel')
        # Allowed still includes the outgoing stream until its queued data drains.
        self.active -= self.leaving
        self.state = 'STOPPING'

    def tick(self):
        now = self.a.clock()
        if self.state == 'READY':
            for ch in self.active:
                if self.a.last_received[ch] is None or now - self.a.last_received[ch] > STREAM_STALE_TIMEOUT_SEC:
                    raise RuntimeError(f'Active channel {ch} stopped streaming')
            return
        if self.state == 'IDLE':
            return
        if now - self.started > STREAM_START_TIMEOUT_SEC:
            raise RuntimeError(f'Pair switch to {self.target} timed out in {self.state}')
        if self.state == 'STOPPING':
            quiet = all(now - max(self.started, self.a.last_received[ch] or self.started)
                        >= SWITCH_QUIET_SEC for ch in self.leaving)
            if not quiet or self.a.device.in_waiting:
                return
            self.a.allowed_channels = set(self.target)
            self.a.clear_traces(self.joining)
            self.start_counts = {ch: self.a.samples[ch] for ch in self.target}
            for ch in self.joining:
                self.a.send(f'sensor {CHANNEL_TO_PORT[ch]} start accel')
            self.active = set(self.target)
            self.state = 'STARTING'
        if self.state == 'STARTING':
            ready = all(self.a.samples[ch] - self.start_counts[ch] >= MIN_START_SAMPLES
                        and now - self.a.last_received[ch] < STREAM_STALE_TIMEOUT_SEC
                        for ch in self.target)
            if ready:
                stamps = [self.a.last_timestamp[ch] for ch in self.target]
                ready = max(stamps) - min(stamps) <= MAX_PAIR_CLOCK_SKEW_SEC * 1e6
            # Incoming bytes are normal during streaming; they must not reset
            # the settle timer. STOPPING retains its separate drain check.
            if not ready:
                self.ready_since = None
                return
            if self.ready_since is None:
                self.ready_since = now
            if now - self.ready_since >= SWITCH_SETTLE_SEC:
                self.state = 'READY'
                print(f'Active pair verified: {self.target}')
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

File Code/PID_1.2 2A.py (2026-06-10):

import serial
import time
import csv
import datetime
import numpy as np
import matplotlib.pyplot as plt
import matplotlib.gridspec as gridspec
from matplotlib.animation import FuncAnimation
from collections import deque

# --- CONFIGURATION ---
PORT = '/dev/tty.usbmodem3646396830331' 
BAUD_RATE = 115200 

# --- SWEEP & CONTROL SETTINGS ---
SWEEP_START_FREQ = 25   
SWEEP_END_FREQ = 300     
SWEEP_STEP_SIZE = 5
TARGET_PEAK_G = 1.0      
MAX_AMPLITUDE = 0.8      
TOLERANCE_PCT = 0.07
STABILITY_WINDOW = 3.0   
UPDATE_INTERVAL = 0.25    
COLLECT_TIME_SEC = 3.0   
WINDOW_SIZE = 100         
ODR_SETTING = 840        # Set to 840Hz for lower sample rate
BMASS = 0.070            # bath mass in kg
DEGREE = "270"             # Degree setting
STINGER_LENGTH = 100         # Stinger gap in millimeters
SPACER = 10               # Spacer thickness in millimeters
APP_VERSION = '1.2'   # Application version included in file names
PHYS_VERSION = '1.4_3Washers'      # Physical system version suffix

def build_csv_filename():
    timestamp = datetime.datetime.now().strftime('%Y-%m-%d_%H-%M-%S')
    version_tag = f"{APP_VERSION}-{PHYS_VERSION}"
    stinger_label = f"Total_Stinger_{STINGER_LENGTH}mm_Spacer_{SPACER}mm"
    return f"{timestamp}_v{version_tag}_vibecheck_sweep_{SWEEP_START_FREQ}-{SWEEP_END_FREQ}Hz_{ODR_SETTING}Hz_{TARGET_PEAK_G}G_{DEGREE}F_{BMASS}kg_{stinger_label}.csv"

CSV_FILENAME = build_csv_filename()

# Initialize physical sensor ports used by this system
INIT_CHANNELS = [0, 1]
PLOT_CHANNELS = [0, 2]

CHANNEL_LABELS = {
    0: "Bath 1 (Z-axis)",
    2: "Bath 2 (Z-axis)"
}

# --- SERIAL & UTILITY ---
device = serial.Serial(PORT, BAUD_RATE, timeout=0.01)

def send_command_sync(cmd, timeout_sec=1.5):
    print(f"Sending: {cmd}")
    device.write(f"{cmd}\n".encode('utf-8')) 
    start_time = time.time()
    while (time.time() - start_time) < timeout_sec:
        line = device.readline().decode('utf-8', errors='ignore').strip()
        if line and any(x in line.lower() for x in ["ack", "ok"]):
            print(f"   -> Board: {line}")
            return line
    return None

def send_command_async(cmd):
    device.write(f"{cmd}\n".encode('utf-8'))

shutdown_initiated = False

def stop_hardware():
    global shutdown_initiated
    if shutdown_initiated:
        return
    shutdown_initiated = True
    print("--- FINAL HARDWARE SHUTDOWN ---")
    send_command_async("wavegen stop")
    for ch in INIT_CHANNELS:
        send_command_async(f"sensor {ch} stop accel")

def get_ac_rms(data_deque):
    """Calculates pure AC RMS. Using np.std inherently strips out static DC bias/gravity offset."""
    if len(data_deque) < 20: return 0.0 # Wait for at least a tiny bit of data
    arr = np.array(data_deque)
    return np.std(arr) 

def get_combined_rms(axis1, axis2):
    return np.sqrt(get_ac_rms(axis1)**2 + get_ac_rms(axis2)**2)

# --- DATA STORAGE ---
sensor_data = {
    chan: {ax: deque(maxlen=WINDOW_SIZE) for ax in ['x', 'y', 'z', 't']}
    for chan in PLOT_CHANNELS
}

# --- CONTROLLER LOGIC ---
class SweepController:
    def __init__(self):
        self.freqs = list(range(SWEEP_START_FREQ, SWEEP_END_FREQ + 1, SWEEP_STEP_SIZE))
        self.idx = 0
        self.state = "INIT"
        self.paused = False
        self.skip_req = False
        self.current_freq = self.freqs[self.idx]
        self.current_amp = 0.0  # Initialized here to ensure it exists for early raw logging
        
        self.Kp, self.Ki, self.Kd = 0.02, 0.004, 0.002
        self.error_sum = 0
        self.last_error = 0
        self.last_tune_time = 0
        self.timer_start = 0
        self.target_rms = TARGET_PEAK_G / np.sqrt(2)

        self.csv_file = open(CSV_FILENAME, 'w', newline='')
        self.csv_writer = csv.writer(self.csv_file)
        
        # UPDATED: New CSV Header for raw data logging
        self.csv_writer.writerow([
            "Timestamp", "Freq", "Drive_Amp", "Channel", "X", "Y", "Z"
        ])

    def get_status_text(self):
        if self.paused: return "PAUSED"
        if self.state == "HOLDING":
            time_left = max(0.0, STABILITY_WINDOW - (time.time() - self.timer_start))
            return f"Holding ({time_left:.1f}s)"
        elif self.state == "COLLECTING":
            time_left = max(0.0, COLLECT_TIME_SEC - (time.time() - self.timer_start))
            return f"Collecting Data ({time_left:.1f}s)"
        elif self.state == "DONE":
            return "SWEEP COMPLETE"
        else:
            return self.state

    def run_tick(self):
        if self.paused or self.state == "DONE": return
        if self.skip_req:
            self.skip_req = False
            self.next_freq()
            return

        now = time.time()
        if self.state == "INIT":
            self.current_amp = 0.005 
            self.error_sum = 0
            send_command_async(f"wavegen set frequency {self.current_freq}")
            send_command_async(f"wavegen set amplitude {self.current_amp}")
            self.state = "TUNING"
            self.last_tune_time = now + 0.5 
            return

        rms_0 = get_ac_rms(sensor_data[0]['z'])
        
        # Wait until the buffer actually has a little data before tuning
        if rms_0 == 0.0:
            return 

        current_rms = rms_0
        error = self.target_rms - current_rms
        in_bounds = abs(error) <= (self.target_rms * TOLERANCE_PCT)

        if self.state == "TUNING":
            if now - self.last_tune_time >= UPDATE_INTERVAL:
                if in_bounds:
                    self.state = "HOLDING"
                    self.timer_start = now
                    print(f"[*] Target {TARGET_PEAK_G}G reached at {self.current_freq} Hz | Final Drive Amp: {self.current_amp:.4f}")
                else:
                    dt = now - self.last_tune_time
                    
                    # Anti-Windup Logic
                    if self.current_amp < MAX_AMPLITUDE or error < 0:
                        self.error_sum += error * dt
                        
                    adj = (self.Kp * error) + (self.Ki * self.error_sum) + (self.Kd * (error - self.last_error)/dt)
                    self.current_amp = max(0.005, min(MAX_AMPLITUDE, self.current_amp + adj))
                    send_command_async(f"wavegen set amplitude {self.current_amp:.4f}")
                    self.last_error = error; self.last_tune_time = now

        elif self.state == "HOLDING":
            if not in_bounds: self.state = "TUNING"
            elif now - self.timer_start >= STABILITY_WINDOW:
                self.state = "COLLECTING"; self.timer_start = now

        elif self.state == "COLLECTING":
            # UPDATED: Removed the old summary CSV logger from here. 
            # Raw data logging is now handled entirely inside `update_data`.
            if now - self.timer_start >= COLLECT_TIME_SEC:
                self.next_freq()
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

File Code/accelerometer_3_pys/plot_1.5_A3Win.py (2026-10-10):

"""VibeCheck three-sensor paired-capture plots, version 1.5 (Windows friendly).

Install: py -m pip install numpy pandas matplotlib scipy
Run: py plot_1.5_A3Win.py "C:/data/sweep.csv" --no-show
With no path: newest sweep beside script, then working folder, then file picker.
Exactly three PNGs: PID/analysis; PID2/bath_z_comparison; PID2/time_traces.
Time traces wrap at 10 frequencies per band, with three sensor rows per band.

AXES: baths vertical Z, planar sqrt(std(X)^2+std(Y)^2); shaker vertical Y,
planar sqrt(std(X)^2+std(Z)^2). Change SHAKER_VERTICAL_AXIS if mounting differs.
All amplitudes are AC RMS (DC removed). Average bath = arithmetic mean of
individual sensor RMS amplitudes, never RMS of averaged time-domain signals.
Bath statistics use BATH_PAIR only; shaker uses SHAKER_PAIR only. Bath 1 from
SHAKER_PAIR is used ONLY for the phase-to-phase reference-stability panel.
Cross-phase transmissibilities are sequential amplitude ratios, not simultaneous
transfer functions. They are unavailable if commanded drive differs across phases.

THD_2-5 (%) = 100*sqrt(A2^2+A3^2+A4^2+A5^2)/A1, using harmonic RMS amplitudes.
Bath THD uses the mean of the two bath amplitudes AT EACH harmonic. This is an
aggregate amplitude-spectrum metric, NOT THD of a spatially averaged waveform.
A timestamp-based least-squares sine/cosine fit includes DC and a linear trend.
The fundamental is fitted near the commanded frequency to reduce leakage bias.
The same harmonic orders are used for every valid point: no silent truncation
at Nyquist. Missing/gapped/undersampled records or weak fundamentals give NaN.
THD excludes broadband noise and harmonics above order 5; it is not THD+N.
Sensor bandwidth, aliasing and timestamp accuracy still limit interpretation.
Definition reference: https://knowledge.ni.com/KnowledgeArticleDetails?id=kA03q000000YHDjCAO&l=en-US

Waveforms show raw sensor X/Y/Z with each full-block mean removed. Both baths
share a time origin from their common capture; shaker uses its own later block.
Relative time in those separate blocks must NOT be used for bath/shaker phase.
Legacy files without Phase are treated as a single simultaneous capture; shaker
and cross-phase diagnostics are unavailable if their channels/phases are absent.
"""
import argparse
import hashlib
import math
from pathlib import Path
import sys
import textwrap
import warnings

import numpy as np
import pandas as pd
from scipy.optimize import minimize_scalar
import matplotlib
if '--no-show' in sys.argv:
    matplotlib.use('Agg')
import matplotlib.pyplot as plt

OUTPUT_DIR = 'PID'
SECOND_OUTPUT_DIR = 'PID2'
SHOW_PLOTS = True
SHAKER_VERTICAL_AXIS = 'Y'
THD_MAX_HARMONIC = 5
MIN_RMS_G = 0.001             # Denominators below this are unavailable, not floored.
MAX_GAP_FACTOR = 1.5         # Relative to median within-block sample interval.
FREQUENCIES_PER_ROW = 10
TRACE_PERIODS = 5
SUMMARY_DPI = 240
TRACE_DPI = 150
COLORS = {'bath1': 'purple', 'bath2': 'darkorange', 'bath': '#d94b42',
          'shaker': '#285a83', 'planar_ratio': '#128572', 'z_transfer': '#9361b4'}


def output_path(csv_filename, suffix, output_dir=OUTPUT_DIR):
    source = Path(csv_filename).resolve()
    folder = source.parent / output_dir
    folder.mkdir(parents=True, exist_ok=True)
    token = hashlib.sha256(source.name.encode('utf-8')).hexdigest()[:8]
    return folder / f'{source.stem[:48]}_{token}_{suffix}.png'


def finish_figure(fig, destination, dpi=SUMMARY_DPI):
    fig.savefig(destination, dpi=dpi, bbox_inches='tight')
    print(f'Saved: {destination}')
    if SHOW_PLOTS:
        plt.show()
    plt.close(fig)
    return destination


def load_sweep_csv(filename):
    df = pd.read_csv(filename, encoding='utf-8-sig')
    df.columns = df.columns.str.strip()
    required = ['Timestamp', 'Freq', 'Drive_Amp', 'Channel', 'X', 'Y', 'Z']
    missing = set(required) - set(df.columns)
    if missing or df.empty:
        raise ValueError(f'Empty CSV or missing columns: {sorted(missing)}')
    numeric = required + [c for c in ('Timestamp_us', 'Window_Start_us', 'Window_End_us') if c in df]
    for c in numeric:
        df[c] = pd.to_numeric(df[c], errors='raise')
        if not np.isfinite(df[c]).all():
            raise ValueError(f'Non-finite values in {c}')
    if (df.Freq <= 0).any() or (df.Channel % 1 != 0).any():
        raise ValueError('Frequency must be positive and channel IDs must be integers')
    if 'Timestamp_us' in df:
        if not np.allclose(df.Timestamp, df.Timestamp_us / 1e6, rtol=0, atol=1e-6):
            raise ValueError('Timestamp and Timestamp_us disagree')
        df['Timestamp'] = df.Timestamp_us / 1e6
    paired = 'Phase' in df
    if paired:
        if not df.Phase.isin(['BATH_PAIR', 'SHAKER_PAIR']).all():
            raise ValueError('Unknown or missing Phase labels')
        valid = ((df.Phase.eq('BATH_PAIR') & df.Channel.isin([0, 2])) |
                 (df.Phase.eq('SHAKER_PAIR') & df.Channel.isin([0, 4])))
        if not valid.all():
            raise ValueError('Unexpected channel in a paired capture')
        for col in ('Step', 'Window_Start_us', 'Window_End_us'):
            if col in df and (df.groupby(['Freq', 'Phase'])[col].nunique() > 1).any():
                raise ValueError(f'Multiple {col} values at the same frequency/phase; do not pool runs')
        if {'Window_Start_us', 'Window_End_us'} <= set(df.columns):
            us = df.Timestamp.to_numpy() * 1e6
            if ((us < df.Window_Start_us - .01) | (us >= df.Window_End_us + .01)).any():
                raise ValueError('Samples outside declared capture windows')
    else:
        df['Phase'] = 'LEGACY'
        warnings.warn('Legacy CSV: no capture phases; treating recorded channels as simultaneous.')
    for key, g in df.groupby(['Freq', 'Phase', 'Channel'], sort=False):
        if (np.diff(g.Timestamp.to_numpy()) <= 0).any():
            raise ValueError(f'Duplicate/backward timestamps in {key}; refusing to reorder records')
    df.attrs['paired'] = paired
    return df


def ac_rms(g, axis):
    return float(g[axis].std(ddof=0)) if len(g) >= 2 else np.nan


def planar(g, vertical):
    axes = [a for a in 'XYZ' if a != vertical]
    return float(np.hypot(ac_rms(g, axes[0]), ac_rms(g, axes[1])))


def safe_ratio(numerator, denominator):
    if not np.isfinite(numerator) or not np.isfinite(denominator) or denominator < MIN_RMS_G:
        return np.nan
    return numerator / denominator
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

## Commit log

2026-04-17 took initial data
    [2026-04-17_19-11-25_vibecheck_sweep_20-220Hz_1660Hz.csv, 2026-04-17_19-13-07_vibecheck_sweep_30-220Hz_1660Hz.csv, 2026-04-17_19-15-36_vibecheck_sweep_30-220Hz_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]
2026-04-21 requirement.txt
    also changed the sampling back to 840 from 1660. This might be personal system limitation. Will explore more later
    [2026-04-21_15-34-18_vibecheck_sweep_30-220Hz_1660Hz.csv, 2026-04-21_15-35-44_vibecheck_sweep_30-220Hz_1660Hz.csv, 2026-04-21_15-37-34_vibecheck_sweep_30-220Hz_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]
2026-04-24 John's Flexure Code Added
    Adapted the numbers in the SprialFlexureShapefactor.py code to produce a 360 degree spiral flexure to replace the current flexures on the shaker and standardize future flexure creation.
2026-05-02 Shaker Live and Specific Plot
    I added the live script and copied the plotting script to give me a script that can take a specific file and give the plot output instead of finding the most recent.
    [2026-05-02_15-48-51_vibecheck_sweep_40-200Hz_840Hz.csv]
2026-05-06 LivePID separation and Plots update
    1.10.1 to 1.10.2 just adds controls for bath mass and flexure degree. LivePID is the previous script PID is the script that only collects data without the live plot. I also changed the plot 6 in the 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
2026-05-06 Start of benchmarking and Orgnaization
    [2026-04-17_19-11-25_vibecheck_sweep_20-220Hz_1660Hz.csv, 2026-04-17_19-13-07_vibecheck_sweep_30-220Hz_1660Hz.csv, 2026-04-17_19-15-36_vibecheck_sweep_30-220Hz_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]
2026-05-07 Reseting Version and Benchmarking
    [2026-05-07_13-05-05_v1.0-1.0_vibecheck_sweep_40-200Hz_840Hz_4.0G_360F_0.427kg.csv]
2026-05-17 Plotting 1.1 update and flies moved
    [2026-05-07_13-05-05_v1.0-1.0_vibecheck_sweep_40-200Hz_840Hz_4.0G_360F_0.427kg.csv]
2026-05-18 Plotting Update 1.2 and PID 1.1
2026-05-24 Data Organization and 2 Accel. Change
    [2026-04-17_19-11-25_vibecheck_sweep_20-220Hz_1660Hz.csv, 2026-04-17_19-13-07_vibecheck_sweep_30-220Hz_1660Hz.csv, 2026-04-17_19-15-36_vibecheck_sweep_30-220Hz_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]
2026-06-01 Stiff Flexure Data and Organization
    [PID_1.2 2A.py]
2026-08-20 3D Print Flies
    3D print STLs and some files move
    [1) Custom PLA Corner Bracket.stl, 10) PLA Base Shaker Attachment.stl, 11) PLA Base Shaker-Stinger Attachment.stl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]
2026-08-20 Fusion Files, 3D Print Files, and Flexure Files
    [1) Custom PLA Corner Bracket.f3d, 10) PLA Base Shaker Attachment.f3d, 11) PLA Base Shaker-Stinger Attachment.f3d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]
2026-08-21 Bambu Files and 3D Print Files Update
    [1) Custom PLA Corner Bracket.gcode.3mf, 1) Custom PLA Corner Bracket.stl, 10) PLA Base Shaker Attachment.f3d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]
2026-08-21 Bambu Plate Files
    [17) PLA Flexure Housing Screw Clamp.gcode.3mf, 5 Plates.3mf, Plate 1.gcode.3mf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]
2026-09-26 Folder rename
    [2026-05-07_11-12-30_v1.0-1.0_vibecheck_sweep_40-200Hz_840Hz_4.0G_360F_0.0622kg.csv, 2026-05-07_11-21-40_v1.0-1.0_vibecheck_sweep_40-200Hz_840Hz_2.0G_360F_0.062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]
2026-09-27 Windows OS switch. Preparation Future Updates
    Switched to Windows computer to test Sampling Rate ability of Vibecheck. It was successful. Future work will be on windows. Updates to come will modify plotting layouts and introduce harmonic distort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
    [2026-09-26_11-51-40_v1.2-1.4_Washers_vibecheck_sweep_150-300Hz_4000Hz_1.0G_180F_0.07kg_Total_Stinger_100mm_Spacer_10mm.csv, Stinger 2.5M Bolt Rod Attatchment (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]
2026-10-04 return to 3 accelerometer testing update
2026-10-04 Readme and 3rd accelerometer folder name change
    [Stinger 2.5M Bolt Rod Attatchment (with sensor).stl]
2026-10-04 corrected readme.md 2
    [Stinger 2.5M Bolt Rod Attatchment (with sensor).stl]
2026-10-10 3 Accelerometers paired py
2026-10-10 1.5 PID and Plotting 3 Accelerometer Python Scripts
